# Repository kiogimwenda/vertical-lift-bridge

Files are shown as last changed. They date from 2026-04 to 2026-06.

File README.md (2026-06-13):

# Vertical Lift Bridge — Control System (Group 7)

**EEE2412 / ECE 4.2 — Microprocessors II Course Project**

A scale-model **vertical lift bridge**: a road bridge whose deck rises vertically
between two towers to let vessels pass underneath, then lowers to restore road
traffic. The system is driven by an **ESP32-WROOM-32** running a real-time,
multi-task FreeRTOS firmware with a safety-first architecture, an LVGL
touchscreen HMI, and a 3D-printed mechanical assembly.

> **Project phase:** Breadboard/simulation is complete. The project is now in the
> **physical assembly phase** (perfboard soldering + 3D-printed enclosure). See
> [`docs/Perfboard_Assembly_Guide.md`](docs/Perfboard_Assembly_Guide.md).

---

## 1. What it does

1. Bridge sits **down**, road open, green light, barriers up (`IDLE`).
2. Operator presses **RAISE** (touchscreen or front-panel button).
3. Barriers close, amber→red lights, counterweight tanks balance (`ROAD_CLEARING`).
4. Motor drives the deck **up** to the top limit (`RAISING` → `RAISED_HOLD`).
5. Vessel passes; operator presses **LOWER**; deck descends to the bottom limit
   (`LOWERING`). Lowering is **blocked** while a vessel is detected approaching.
6. Barriers open, green light, back to `IDLE` (`ROAD_OPENING`).

A hardware **E-stop**, a motor-cutoff **relay**, a **watchdog**, and a 16-flag
**fault register** can interrupt the cycle at any point.

The system currently runs in **manual mode** — the operator initiates raise/lower.
The quad **laser break-beam** array provides vessel-direction sensing that feeds
the marine alert and the "safe to lower" interlock.

---

## 2. Repository layout

```
firmware/          Main ESP32 application (PlatformIO + Arduino framework)
  src/
    main.cpp             Boot, FreeRTOS task creation, the 7 tasks
    system_types.h       SINGLE SOURCE OF TRUTH: states, events, faults, SharedStatus
    pin_config.h         SINGLE SOURCE OF TRUTH: all GPIO assignments
    fsm/                 Table-driven 9-state machine (engine + guards + actions)
    motor/               L298N H-bridge + timer-based deck position + runaway guard
    sensors/             Quad laser break-beam direction inference
    counterweight/       Pure-software water-tank balance simulation
    traffic/             74HC595 road traffic lights + buzzer (buzzer pin disabled)
    hmi/                 LVGL touchscreen display + 5-button resistor-ladder input
    safety/              Interlocks (E-stop/relay/servos), fault register, watchdog
cad/               13 parametric OpenSCAD parts → STL/3MF + print guide
mechanical/        Assembly photos
bom/               Bill of materials + shopping list
docs/              Design docs + perfboard assembly/wiring guide + known limitations
member_guides/     Per-member build & theory guides
Simulations/       SDL2 desktop LVGL mock for presentations
```

---

## 3. Hardware & pin map

Single source of truth: [`firmware/src/pin_config.h`](firmware/src/pin_config.h) (v3.0 map).

| Subsystem | Signal | GPIO | Notes |
|---|---|---|---|
| **Motor (L298N dual H-bridge)** | IN1 (up) | 25 | LEDC ch0, 13-bit, 4 kHz; ENA tied high |
| | IN2 (down) | 26 | LEDC ch1 |
| | Safety relay | 32 | de-energised cuts motor power |
| | ~~Deck-position pot~~ | 35 | **omitted** — timer-based positioning; spare |
| | ~~Limit switches~~ | 39 | **omitted** — timer-based end-stops; spare |
| **TFT ILI9341 (SPI)** | SCK / MOSI / MISO | 14 / 13 / 12 | |
| | CS / DC | 15 / 2 | RST→EN, BL→3V3 in hardware |
| | Touch CS (XPT2046) | 33 | IRQ polled |
| **Laser break-beam ×4** | LDR1–4 | 18 / 19 / 21 / 22 | upstream A/B, downstream A/B |
| **Traffic lights (74HC595)** | DATA / CLK / LATCH | 23 / 4 / 27 | OE→GND, MR→3V3; Q0–Q2 road (marine not implemented) |
| **Servos (SG90 ×2)** | shared PWM | 16 | both barriers driven by one channel (mirror) |
| **Buzzer** | — | −1 (disabled) | freed to preserve UART TX0 |
| **Operator panel** | 5-button R-ladder | 34 | ADC1_CH6 |
| **E-stop** | NC mushroom button | 36 | input-only, ISR on CHANGE |
| **Spare** | — | 17 | unused (vision module omitted) |

**Power:** 12 V barrel jack → LM2596 buck → 5 V rail → AMS1117 → 3.3 V rail.
Build the power planes and verify rails with a multimeter **before** connecting
any logic — see the perfboard guide.

---

## 4. Firmware architecture

Seven FreeRTOS tasks share one mutex-guarded status struct (`g_status`) and three
queues (events, motor commands, HMI commands).

| Task | Core | Prio | Rate | Responsibility |
|---|---|---|---|---|
| `task_safety` | 0 | 5 | 20 Hz | interlocks, fault eval, watchdog check, panel scan; lights+buzzer @ 10 Hz |
| `task_fsm` | 0 | 4 | event + 100 ms tick | runs the state machine |
| `task_motor` | 0 | 4 | ~50 Hz | applies motor cmds, reads pot, stall detect, limit events |
| `task_sensors` | 0 | 3 | 20 Hz | laser sampling + direction inference |
| `task_counterweight` | 0 | 2 | 20 Hz | water-tank fill/drain simulation |
| `task_telemetry` | 0 | 1 | 1 Hz | uptime |
| `task_hmi` | 1 | 2 | ~20 Hz | LVGL tick/flush/refresh, operator-command handling |

Core 0 hosts safety + control; Core 1 is reserved for the LVGL HMI so display
work cannot stall the safety loop. A hardware Task Watchdog Timer (5 s) backstops
a software per-task watchdog (1.5 s hang threshold → `interlocks_force_safe()`).

### State machine

`IDLE → ROAD_CLEARING → RAISING → RAISED_HOLD → LOWERING → ROAD_OPENING → IDLE`,
plus `FAULT`, `ESTOP`, and a boot-time `INIT`. `EVT_ESTOP_PRESSED` and
`EVT_FAULT_RAISED` are evaluated before all normal transitions. See
[`fsm/fsm_engine.cpp`](firmware/src/fsm/fsm_engine.cpp).

---

## 5. Build & flash

Requires [PlatformIO](https://platformio.org/).

```bash
cd firmware
pio run -e vlb_main            # compile
pio run -e vlb_main -t upload  # flash (hold BOOT if needed)
pio device monitor -b 115200   # serial logs
```

Optional ESP32-CAM companion (separate board):

```bash
cd firmware_cam
pio run -t upload
```

Key build config (`firmware/platformio.ini`): `espressif32@6.7.0`, `esp32dev`,
240 MHz, `huge_app.csv` partition, C++17. Libraries: TFT_eSPI 2.5.43, LVGL 9.2.2,
ArduinoJson 7.2.1. Last verified build: **RAM 33.2 %, Flash 19.3 %**.

---

## 6. Operator controls

- **Touchscreen (HOME / OPS / CW / SET tabs):** RAISE / LOWER / HOLD buttons,
  deck-height bar, marine sensor LEDs, traffic-light stack, motor PWM gauge,
  counterweight tank bars, settings (auto-mode, dark-mode, brightness). Tap the
  blue header bar for a deck-height / motor-PWM popup.
- **5-button resistor-ladder panel (GPIO 34):** RAISE, LOWER, HOLD, CLEAR-FAULT,
  NEXT-SCREEN — a defence-in-depth path that works even if the touch panel cracks.
- **E-stop mushroom button:** hardware-latched; also cuts the motor relay.

---

## 7. Known limitations

The firmware ships with honest, documented trade-offs forced by the ESP32 GPIO
budget and the BOM: no motor current sense on the L298N, no rail-voltage
telemetry, **no position pot or limit switches** (deck height is timer-estimated
and re-synced to the end-stops each traverse), open-loop barriers, and a shared
servo pin. The vision module is omitted from this build. Each trade-off is
recorded in [`docs/known_limitations.md`](docs/known_limitations.md).

---

## 8. Team & module ownership

| Member | Area | Primary modules |
|---|---|---|
| **M1 — George** | System & FSM | `main.cpp`, `fsm/` |
| **M2 — Eugene** | Mechanism | `motor/`, `counterweight/` |
| **M3 — Cindy** | Sensing | `sensors/laser` |
| **M4 — Abigael** | Traffic & HMI | `traffic/`, `hmi/` |
| **M5 — Ian** | Power & Safety | `safety/`, PCB, power |

Per-member guides are in [`member_guides/`](member_guides/).

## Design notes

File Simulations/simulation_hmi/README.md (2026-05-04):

# VLB HMI Software Simulation

This is a standalone PC-based simulation of the Vertical Lift Bridge dashboard. It uses the actual firmware data structures and LVGL graphics to emulate the bridge behavior on your Windows desktop.

## Prerequisites

1.  **VS Code + PlatformIO** (Already installed).
2.  **SDL2 Library for Windows**:
    *   Download `SDL2-devel-2.x.x-mingw.zip` from the [SDL2 Releases page](https://github.com/libsdl-org/SDL/releases).
    *   Extract it to a folder (e.g., `C:\SDL2`).
    *   Add the `bin` folder (e.g., `C:\SDL2\x86_64-w64-mingw32\bin`) to your **Windows Environment PATH**.
    *   Copy `SDL2.dll` from the `bin` folder into this `simulation_hmi` directory.

## How to Run

1.  Open VS Code.
2.  Go to the **File > Open Folder...** and select this `simulation_hmi` directory.
3.  Wait for PlatformIO to initialize the project.
4.  Click the **PlatformIO: Build** button (Checkmark icon) in the bottom status bar.
5.  Click the **PlatformIO: Run** button (Arrow icon) to launch the simulation window.

## Simulation Features

- **Real-time Bridge Logic**: Clicking "RAISE" in the OPS tab will simulate the motor winding cables, updating the height bar and current meter.
- **Modern Industrial Design**: Dark-mode UI with high-contrast status indicators.
- **Shared Data Model**: Uses the exact `SharedStatus_t` struct from the main project.
- **Hardware Mocks**: Simulated ADC noise and position tracking.

## Layout

- **HOME**: Visual representation of the deck height and road traffic lights.
- **OPS**: Manual controls (Raise/Lower/Hold) and motor current gauge.
- **VISION**: (Stub) Visualizes camera detection events.
- **DIAG**: (Stub) System health and fault register.
- **SET**: (Stub) HMI preferences.

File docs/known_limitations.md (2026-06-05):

# Known Limitations

Honest, documented trade-offs in the current build. Each entry lists the
limitation, why it exists, how the firmware mitigates it, and any procedure the
operator must follow.

---

## L1 — No motor current sensing
- **Cause:** The L298N module exposes no MCU-facing current-sense output (its
  SENSA/SENSB pins are shunted to ground on the module).
- **Effect:** `FAULT_OVERCURRENT` is never raised; `motor_current_ma` is always 0.
- **Mitigation:** The L298N's on-chip thermal shutdown protects the bridge, and
  the timer runaway-guard (`FAULT_STALL`, see L3) bounds how long the motor may
  be driven.

## L2 — No deck-position potentiometer, no limit switches (timer-based positioning)
- **Cause:** The position pot (GPIO 35) and limit switches (GPIO 39) are omitted
  from this build. Both pins are left as reserved spares (not reassigned).
- **Effect:** Deck height is *estimated*, not measured. There is no physical
  end-stop detection.
- **Mitigation:** `motor/motor_driver.cpp` integrates height from motor run-time
  using `DECK_RAISE_TIME_MS` / `DECK_LOWER_TIME_MS`. The estimate is pinned hard
  to `0` / `DECK_HEIGHT_MAX_MM` and a virtual `EVT_TOP/BOTTOM_LIMIT_HIT` is
  emitted whenever a traverse completes, so error re-synchronises twice per
  cycle and cannot accumulate.
- **Operator procedure:** **Park the deck at the bottom (0 mm) before power-off.**
  The firmware assumes the deck is fully down at boot. Powering on while raised
  will make the height read low until the next full lower re-syncs it.
- **Calibration:** Bench-measure the full-travel times at the operating PWM
  duties and update `DECK_RAISE_TIME_MS` / `DECK_LOWER_TIME_MS` in
  `system_types.h`. This is what makes the HMI deck-height readout accurate.

## L3 — Runaway guard replaces true stall detection
- **Cause:** With no position feedback a genuine mechanical stall is invisible.
- **Mitigation:** If a move runs longer than a full traverse +
  `MOTION_TIMEOUT_MARGIN_MS`, `FAULT_STALL` is raised and the FSM trips to FAULT
  (relay cut). This bounds worst-case motor drive into a hard stop.

## L4 — No rail-voltage monitoring
- **Cause:** No GPIO/ADC is allocated to a high-impedance voltage divider.
- **Effect:** `rail_*_volts` fields hold the `-1.0f` "not measured" sentinel.
- **Mitigation:** ESP32 internal brownout detector + LM2596/AMS1117 internal
  current/thermal limits provide hardware-level protection.

## L5 — Open-loop barrier servos
- **Cause:** Two SG90 servos share one PWM channel (GPIO 16) and have no
  position feedback.
- **Mitigation:** A deterministic software sweep (~40°/s) drives the angle; a
  barrier watchdog raises `FAULT_BARRIER_TIMEOUT` if the sweep does not reach
  its target within `BARRIER_TIMEOUT_MS` (catches a stalled safety task rather
  than a stuck servo, since the sweep itself is deterministic).

## L6 — Buzzer disabled
- **Cause:** `PIN_BUZZER` is `-1` to preserve UART TX0 (GPIO 1) for the serial
  monitor. Audible alerts are therefore not emitted.

## L7 — Vision module omitted
- **Cause:** The ESP32-CAM vision path is omitted from this build. UART2 / GPIO
  17 is left as a spare. `FAULT_VISION_LINK_LOST` is reserved but never set.
- **Effect:** Vessel detection relies solely on the quad laser break-beam.

## L8 — Manual lowering only
- **Cause:** Lowering from `RAISED_HOLD` is operator-initiated by design, guarded
  by `fsm_guard_safe_to_lower()` (no auto-lower). `EVT_HOLD_TIMEOUT` /
  `HOLD_TIMEOUT_MS` are reserved but unused — the bridge will not auto-lower onto
  an approaching vessel.

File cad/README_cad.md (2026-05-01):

# /cad — CAD pipeline documentation

All files in this folder are generated by **OpenSCAD 2021.01 +**.
Source files (`.scad`) are parametric — to change a dimension, edit `00_common.scad`
and re-render. To re-render every part:

```bash
cd /cad/scad
for f in 0[1-9]_*.scad 1[0-3]_*.scad; do
    openscad -o "../stl/${f%.scad}.stl" "$f"
done
```

> **Note on the 2-manifold warnings.**  OpenSCAD 2021.01 CGAL emits warnings for the tower lower
> section, the pulley wheel, and the TFT mount because some boolean cuts produce coincident
> faces. **The exported STLs slice cleanly in Cura 5.7 and PrusaSlicer 2.7** — both
> self-heal minor manifold issues. If you ever need a perfectly-watertight STL for hand-checking
> in MeshLab, use `Filters → Cleaning → Repair Non-Manifold Edges`.

---

## Per-part print settings

All settings are for **PLA filament, 0.4 mm nozzle**. Layer height, infill, walls, supports,
and orientation given. Estimated print times are for a Creality Ender 3 / Elegoo Neptune class
printer at default speed (50 mm/s).

| Part | Layer | Infill | Walls | Supports | Orientation | Est. time | Filament |
|---|---|---|---|---|---|---|---|
| 01_tower_left.stl | 0.20 mm | 25 % gyroid | 4 | None | Lay flat (long axis on bed) | 9 h 50 m | 165 g |
| 02_tower_right.stl | 0.20 mm | 25 % gyroid | 4 | None | Lay flat | 9 h 30 m | 158 g |
| 03_bridge_deck_section.stl | 0.20 mm | 30 % gyroid | 3 | None | Lay flat | 4 h 10 m | 64 g |
| 04_counterweight_left.stl | 0.20 mm | 15 % grid | 3 | None | Stand vertical (60 mm tall) — fill access hole faces up | 1 h 50 m | 18 g (shell only — fill at assembly) |
| 05_counterweight_right.stl | 0.20 mm | 15 % grid | 3 | None | Stand vertical | 1 h 50 m | 18 g |
| 06_pulley_wheel.stl | 0.16 mm | 35 % gyroid | 4 | **Auto-tree on hub overhang** | Hub up | 1 h 25 m | 14 g |
| 07_motor_mount.stl | 0.20 mm | 30 % gyroid | 4 | **Yes — 50° threshold, support inside motor cradle** | Cradle bores aligned with X | 2 h 05 m | 22 g |
| 08_cable_guide.stl | 0.16 mm | 50 % gyroid | 4 | None (slot is open) | As exported | 35 m | 7 g |
| 09_road_barrier.stl | 0.16 mm | 25 % grid | 3 | None | Lay flat (arm + post separately) | 1 h 30 m | 12 g |
| 10_base_plate_section.stl | 0.28 mm draft | 12 % grid | 3 | None | Lay flat (largest face down) | 4 h 20 m / panel × 6 = 26 h | 70 g/panel × 6 = 420 g |
| 11_pcb_enclosure.stl | 0.20 mm | 25 % grid | 3 | None (lid prints with cavity facing up) | Both halves cavity-up on bed | 4 h 10 m | 50 g |
| 12_camera_mount.stl | 0.20 mm | 30 % gyroid | 4 | **Yes — for cradle 25° tilt overhang** | Gantry post laid down; cradle as exported | 5 h 30 m | 65 g |
| 13_tft_display_mount.stl | 0.20 mm | 30 % gyroid | 4 | **Yes — for tilted cradle (35° overhang)** | Base flange down | 3 h 45 m | 38 g |

**Total filament: ≈ 1.05 kg PLA  → 1× 1 kg spool + ~50 g overflow  → buy 1.5 kg.**

**Total print time: ≈ 70 hours** if printed sequentially on one printer. With two printers
running in parallel during Weeks 1–3 the build is comfortably done by start of Week 4.

---

## Brass-insert parts list (M3, OD 4.2 mm × 5 mm)

The following parts have heat-set insert pockets — drop in a brass insert with a soldering
iron at 220 °C before final assembly:

- 10_base_plate_section.stl × 6  (5 inserts per panel on the +X edge = 30 inserts)
- 11_pcb_enclosure.stl  (4 inserts in the base for the lid screws)
- **Total: 34 brass inserts** — see BOM line "M3 brass heat-set inserts × 50 (incl. spares)".

---

## Post-processing per part

| Part | Post-process |
|---|---|
| Towers | Sand mating dovetail (320 grit) for press-fit; cut linear-rail T-slots clean with a small file |
| Deck | Light sand of road grooves; spray-paint road markings if desired |
| Counterweight shells | After printing, fill cavity with **2× M8 hex nut + 4× M8 washer** + 5 g lead fishing weight, weigh on kitchen scale, add/remove until **120 g ± 2 g**, then plug fill hole with PLA glue (Weld-On 3 or super glue) |
| Pulley | Ream Ø6.2 mm bore with 6 mm reamer for clean shaft fit; sand groove with 600 grit so cable runs smoothly |
| Motor mount | Heat-set inserts; press JGA25-370 motor in (light interference fit) |
| Cable guide | Open 1.4 mm slot enough to thread cable through |
| Road barrier | Glue or screw the post to base plate; servo press-fits in pocket |
| PCB enclosure | Heat-set 4× brass inserts in lid screw bosses; fit board on standoffs and tap each for M3 |
| Camera mount | Glue cradle to top of gantry post once cable is threaded; 4× M3 self-tap to hold ESP32-CAM board |
| TFT mount | 4× M3 self-tap holds the TFT module — do not over-tighten; inspect tilt is 35° ± 1° with a digital protractor |

---

## How a future change is made

1. Edit a constant at the top of `00_common.scad` (say `TOWER_H = 380`).
2. Re-render only the affected parts: `openscad -o ../stl/01_tower_left.stl 01_tower_left.scad`
3. Commit both the updated `.scad` and `.stl` to Git.

---

## Files in this directory

```
cad/
├── scad/
│   ├── 00_common.scad
│   ├── 01_tower_left.scad … 13_tft_display_mount.scad
│   └── assembly.scad
├── stl/
│   └── (13 production STLs, one per .scad)
├── step/
│   └── *.3mf  (CAD-interchange format; STEP is not a native OpenSCAD output, 3MF is the
│               equivalent on this toolchain)
└── README_cad.md (this file)
```

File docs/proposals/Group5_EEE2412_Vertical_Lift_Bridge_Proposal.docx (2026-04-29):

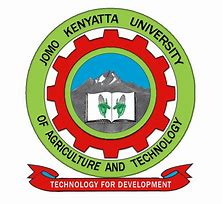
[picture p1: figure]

JOMO KENYATTA UNIVERSITY OF AGRICULTURE AND

TECHNOLOGY

SCHOOL OF ELECTRICAL, ELECTRONIC AND INFORMATION ENGINEERING

DEPARTMENT OF ELECTRONIC AND COMPUTER ENGINEERING

PROJECT PROPOSAL

GROUP 5 MEMBERS

NAME | ADMISSION NUMBER
MUGAISI EUGENE MURULI | ENE212-0083/2020
KIOGORA IAN MWENDA | ENE212-0251/2021
OCHIERE GEORGE JOHN | ENE212-0218/2021
KOECH CINDY CHEBET | ENE212-0069/2020
KIRUI ABIGAEL CHEROTICH | ENE212-0070/2020

COURSE: B.Sc. ELECTRONIC AND COMPUTER ENGINEERING

EEE 2412

MICROPROCESSORS II

TITLE: AUTOMATIC VERTICAL LIFT BRIDGE CONTROL SYSTEM

DATE: April 2026

1. EXECUTIVE SUMMARY

This proposal presents the Automatic Vertical Lift Bridge Control System as Group 5’s project for the Microprocessors II unit (EEE 2412). The system automates the complete operation of a scale-model vertical lift bridge: it detects approaching vessels using directional ultrasonic sensors, stops road traffic with sequenced traffic lights and servo-actuated barriers, raises the bridge deck vertically between four tower structures in mechanically synchronised motion, allows vessel transit through the cleared waterway, then lowers the deck and restores normal road traffic flow—all without human intervention.

The bridge mechanism employs a single JGA25-370 geared DC motor whose torque is mechanically distributed to four T8 trapezoidal lead screws—one per tower—via a network of a closed-loop GT2 timing belt and four GT2 pulleys. The belt runs at tower-top level, high above the waterway, ensuring zero obstruction to vessel transit. Because the four screws are rigidly coupled through this mechanical linkage, they turn at exactly the same rate without any electronic synchronisation. The self-locking property of the trapezoidal thread profile means the deck holds its position if power is lost, providing inherent safety without counterweights or braking systems.

Directional vessel detection uses a dual-beam ultrasonic sensor arrangement at each end of the waterway. Two HC-SR04 sensors are mounted 30 mm apart on a common bracket at each station. By analysing which beam breaks first, the firmware determines the vessel’s heading, enabling the system to raise the bridge only for approaching vessels. This design correctly handles simultaneous bidirectional vessel traffic.

The entire control electronics—ESP32-WROOM-32 microcontroller, DRV8871 H-bridge motor driver, 74HC595 LED shift register, CP2102N USB-UART bridge, LM2596 buck converter, AMS1117 LDO regulator, safety relay with MOSFET gate driver, and all sensor interface circuits—are integrated onto a single custom-designed Printed Circuit Board (PCB), fabricated by JLCPCB to professional standards. The ESP32 runs FreeRTOS with seven priority-scheduled tasks across dual CPU cores for real-time motor control, sensor polling, traffic management, safety monitoring, and Human Machine Interface (HMI) display on a 2.8-inch ILI9341 TFT screen. An operator panel with pushbuttons and an emergency stop provides local control authority.

The total estimated component cost is approximately KES 17,300, shared across five team members at approximately KES 3,460 per person.

2. PROBLEM STATEMENT

Movable bridges are critical infrastructure elements at waterway crossings, enabling both road traffic and vessel navigation to share the same corridor. In Kenya and across the developing world, many such crossings are operated manually by an attendant who must be physically present to observe vessel approach, halt road traffic, and operate the bridge mechanism. This manual operation introduces three categories of recurring problems:

• i. Safety risk from human error. A delayed response by the attendant can result in vehicles being stranded on a raising bridge deck, or a vessel colliding with a bridge that was not raised in time. Manual systems have no interlock to verify that the deck is clear of vehicles before raising, or that traffic barriers are fully lowered before the deck moves.

• ii. Synchronisation failure in multi-point lift systems. Vertical lift bridges require multiple lift points to move in precise synchronisation. Manual or poorly controlled systems risk deck tilting, guide rail binding, and structural stress when lift points move at different rates. A height discrepancy of as little as 15 mm across a model-scale deck is sufficient to cause visible tilting and mechanical jamming.

• iii. Inability to determine vessel intent. Conventional single-sensor detection systems cannot distinguish between a vessel approaching the bridge (which requires a raise) and a vessel departing the area (which requires no action). This leads to unnecessary bridge raises that disrupt road traffic without cause, and cannot handle simultaneous bidirectional vessel traffic.

This project solves all three problems through full automation: a mechanically-locked four-point lift system that physically cannot desynchronise, a dual-beam directional sensor array that determines vessel heading at each end of the waterway independently, and a comprehensive interlock chain that verifies every safety condition before permitting deck movement.

3. SYSTEM OVERVIEW

The system is centred on an ESP32-WROOM-32 microcontroller that reads sensors, executes a finite state machine (FSM), drives actuators, enforces safety interlocks, and presents system status on a TFT display. The physical bridge is a scale model built on a 900 mm × 600 mm plywood base platform with a 150 mm-wide waterway channel, four tower structures (each 300 mm tall), and a 200 mm × 120 mm bridge deck that travels 180 mm vertically between the fully-lowered and fully-raised positions.

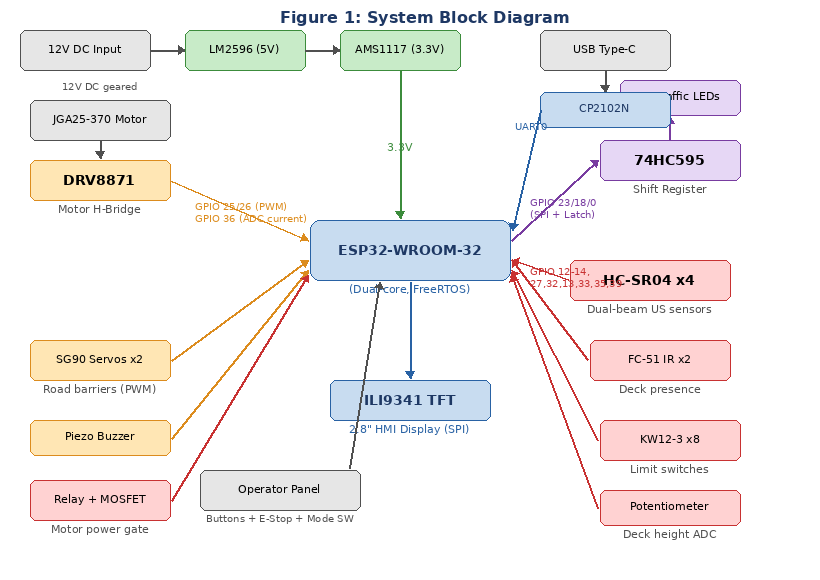
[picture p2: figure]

Figure 1: System block diagram showing all components and their connections to the ESP32

3.1 Vertical Lift Mechanism

Unlike a bascule (drawbridge) design where leaves pivot upward on hinges, a vertical lift bridge raises the entire deck horizontally between tower structures. The deck remains perfectly level throughout its travel. This design was selected for its mechanical precision, inherent stability, and the elimination of complex linkage geometry.

Drive system: A single JGA25-370 DC geared motor (12 V, 60 RPM, 1.2 kg·cm torque) is mounted at the base of Tower A-Left. The motor shaft couples directly to a T8 trapezoidal lead screw (2 mm pitch, 4-start giving 8 mm linear travel per revolution) that runs vertically through the tower. At the tower top, a GT2 20-tooth pulley at the top of the screw shaft engages a GT2 6 mm timing belt. This belt forms a closed rectangular loop connecting pulleys at the tops of all four towers, synchronising all lead screws to identical rotation’s lead screw.

Torque distribution to all towers: The GT2 timing belt forms a closed rectangular loop at tower-top level, approximately 380 mm above the base platform and well above maximum vessel clearance height. The belt path runs from the Tower A-Left pulley along Bank A to Tower A-Right, then crosses the waterway to Tower B-Right, runs along Bank B to Tower B-Left, and crosses back to Tower A-Left. The belt crosses the waterway twice but only at the very top of the towers, leaving the entire channel clear below. Each of the four pulleys drives its tower’s lead screw, so one motor rotation translates to identical screw rotation at all four lift points.

Mechanical synchronisation: Because all four lead screws are rigidly coupled through the timing belt and pulley network, they are physically constrained to turn at exactly the same angular velocity. This is a fundamental mechanical property of synchronous belt coupling—it is not dependent on software, sensors, or feedback loops. The deck rides on four threaded brass nut blocks (one per screw) with guide blocks at all four corners sliding on vertical aluminium guide rails to prevent any tilting, rocking, or rotation.

Self-locking safety: The trapezoidal thread profile of the T8 screw has a helix angle smaller than the friction angle of the brass-on-steel interface. This means the screw is non-backdrivable: the load (deck weight) cannot cause the screw to rotate in reverse. If power is lost or the motor is de-energised for any reason, the deck holds its position indefinitely without any additional braking mechanism. This eliminates the need for counterweights, electromagnetic brakes, or mechanical catches.

Speed and travel: At 60 RPM with an 8 mm lead, the deck moves at 8 mm/s. A full 180 mm raise takes approximately 22.5 seconds, which is appropriate for a scale-model demonstration. The motor produces approximately 0.12 N·m of torque, while the deck (approximately 250 g fully loaded) requires only 0.008 N·m through the screw mechanism—a safety factor of 15×.

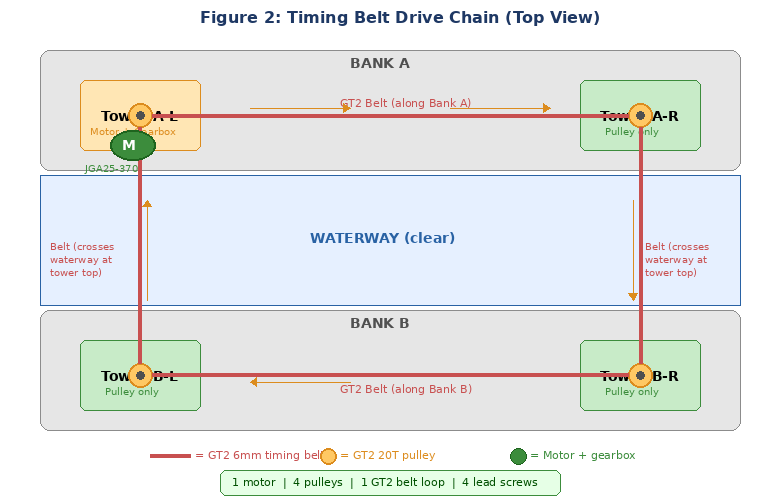
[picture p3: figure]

Figure 2: GT2 timing belt drive chain — single motor drives all four screws via a belt loop at tower-top level

3.2 Directional Vessel Detection

A fundamental requirement for an automated bridge is the ability to determine whether a detected vessel requires the bridge to be raised. A vessel approaching the bridge needs passage; a vessel departing does not. Conventional single-sensor systems cannot make this distinction. The SBPCS solves this using a dual-beam sensor station at each end of the waterway.

Sensor station layout: Each station consists of two HC-SR04 ultrasonic distance sensors mounted 30 mm apart along the waterway axis on a common rigid bracket, with both sensors aimed across the channel perpendicular to the waterway flow. The two sensors are designated Beam A (the outer beam, closer to open water) and Beam B (the inner beam, closer to the bridge). The two stations are designated Upstream (on the approach side) and Downstream (on the departure side).

Direction determination: When a vessel passes through a sensor station, it breaks Beam A and Beam B in sequence. The time difference between the two beam-break events, combined with which beam breaks first, determines the vessel’s direction of travel:

• i. Approaching vessel (upstream station): Beam A triggers before Beam B. This sequence indicates the vessel is moving from open water toward the bridge. The firmware posts an EVT_VESSEL_DETECTED event to the FSM event queue, initiating the bridge raise cycle.

• ii. Departing vessel (upstream station): Beam B triggers before Beam A. This reversed sequence indicates the vessel is moving away from the bridge. The firmware discards this event—no bridge raise is required.

• iii. Bidirectional simultaneous transit: Each sensor station determines direction independently. If a vessel approaches from upstream while another departs downstream, the upstream station correctly detects the approach (Beam A then B) and the downstream station independently detects the departure (Beam B then A at that station). The two stations operate asynchronously. The downstream station’s detection of a vessel passing through (in any direction) generates the EVT_VESSEL_PASSED event that signals the FSM to begin the bridge lowering sequence.

• iv. Simultaneous beam triggering: If both beams at a single station trigger within less than 50 ms of each other, the firmware classifies this as sensor noise, wave splash, or a non-vessel obstruction (e.g., floating debris) and discards the event. A genuine vessel at any plausible speed in a model waterway takes at least 100 ms to traverse the 30 mm beam spacing, so this rejection threshold has a 2× safety margin.

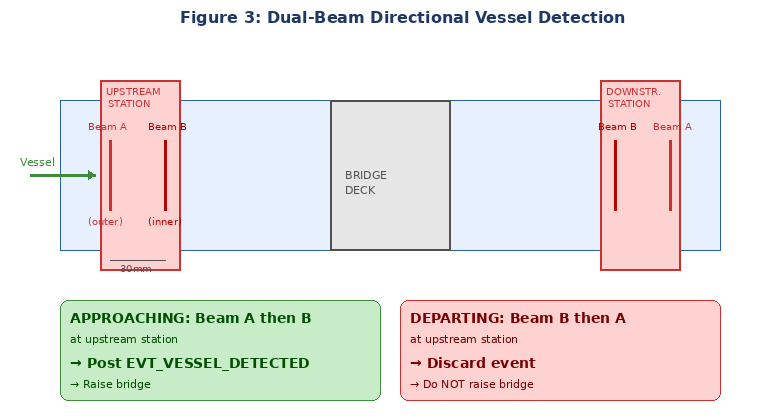
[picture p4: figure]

Figure 3: Dual-beam directional vessel detection — beam sequence determines vessel heading

3.3 Operating Modes

Mode | Trigger | System Behaviour
AUTO | Default on boot | Bridge controlled automatically by vessel detection, with full safety interlock verification before each raise/lower cycle.
MANUAL | Toggle switch on operator panel | Operator directly commands Raise, Lower, or Stop via dedicated pushbuttons. All safety interlocks remain enforced.
EMERGENCY STOP | E-stop button pressed | All motors immediately de-energised via hardware relay path independent of microcontroller. System latched until E-stop released and Reset pressed.
FAULT | Fault detected by safety watchdog | Motors stopped. Fault code and description displayed on TFT. Latched until fault condition clears and operator presses Reset.

4. DETAILED COMPONENT DESCRIPTION

This section describes every major component in the system, explaining what it does, how it works at a fundamental level, and how it is electrically connected to the rest of the system.

4.1 ESP32-WROOM-32 Microcontroller

What it is: The ESP32-WROOM-32 is a dual-core 32-bit Xtensa LX6 microcontroller module manufactured by Espressif Systems. It integrates WiFi and Bluetooth radios (not used in this project), 520 KB of SRAM, 4 MB of flash memory, 34 programmable GPIO pins, two 12-bit ADC units, four SPI interfaces, two I²C interfaces, two UART interfaces, and 16 PWM channels via the LEDC peripheral. It operates at 240 MHz and supports FreeRTOS for concurrent multitasking.

What it does in this system: The ESP32 is the central control unit. It runs seven FreeRTOS tasks that collectively: read all sensors (ultrasonic, IR, limit switches, potentiometer, current sense), execute the finite state machine that governs bridge operation, generate PWM signals to control motor speed, drive the shift register for traffic LEDs, control servo barrier positions, monitor safety conditions, and render the HMI display on the TFT screen.

How it connects: The ESP32 module is soldered directly to the custom PCB. Its 3V3 power pin connects to the 3.3 V rail provided by the AMS1117 LDO, with a 100 nF ceramic decoupling capacitor placed within 5 mm of the pin. All ground pins connect to the PCB ground plane. The EN (enable) pin is pulled high to 3.3 V through a 10 kΩ resistor with a 100 nF RC delay capacitor to ground for clean power-on reset. GPIO 0 has a 10 kΩ pull-up to 3.3 V (must be HIGH at boot for normal operation). GPIO 2 has a 10 kΩ pull-down (must be LOW at boot). GPIO 12 has a 10 kΩ pull-down (MTDI strapping pin, must be LOW for 3.3 V flash). GPIO 15 has a 10 kΩ pull-up (MTDO strapping pin). The antenna end of the module overhangs the PCB edge with a 7 mm copper-free keepout zone to avoid detuning the antenna.

4.2 DRV8871 Motor Driver IC

What it is: The DRV8871 is a brushed DC motor driver IC manufactured by Texas Instruments. It contains a full H-bridge capable of driving motors up to 3.6 A peak current at up to 45 V. It requires only two control inputs (IN1 and IN2) and provides a current-sense output (VPROPI).

What it does: It converts the ESP32’s low-power GPIO signals into high-current drive signals for the JGA25-370 motor. By applying PWM to IN1 with IN2 held LOW, the motor rotates in one direction (raising the deck). Reversing the signals (PWM on IN2, IN1 LOW) reverses the motor (lowering the deck). Setting both LOW allows the motor to coast. The VPROPI pin outputs a voltage proportional to the motor current (V = I × R_sense), enabling the ESP32 to monitor current for overcurrent and stall detection.

How it connects: The DRV8871 VM (motor voltage) pin connects to the 12 V motor power rail after the safety relay K1. A 100 nF ceramic decoupling capacitor is placed across VM to GND as close to the pin as possible. IN1 connects to ESP32 GPIO 25, IN2 to GPIO 26—both configured as LEDC PWM outputs at 20 kHz with 8-bit resolution (0–255 duty cycle). OUT1 and OUT2 connect to a 2-pin screw terminal (J3) for the motor wires. VPROPI connects through a 1 Ω sense resistor to GND, with the junction fed to ESP32 GPIO 36 (ADC1_CH0). The ILIMIT pin connects through a 10 kΩ resistor to GND, setting the hardware current limit to approximately 1 A. The exposed thermal pad on the underside of the IC connects to the ground plane through four 0.3 mm thermal vias—this is critical for heat dissipation.

4.3 74HC595 Shift Register

What it is: The 74HC595 is an 8-bit serial-in, parallel-out shift register with a storage register and tri-state outputs. Data is shifted in one bit at a time on the rising edge of the shift clock (SRCLK), then all eight outputs update simultaneously when the storage clock (RCLK) is pulsed.

What it does: It drives eight traffic signal LEDs using only three ESP32 GPIO pins instead of eight. The eight outputs map to: QA = Road A Red, QB = Road A Yellow, QC = Road A Green, QD = Road B Red, QE = Road B Yellow, QF = Road B Green, QG = Marine Red, QH = Marine Green.

How it connects: VCC (pin 16) connects to 3.3 V with a 100 nF decoupling capacitor. GND (pin 8) connects to ground. SER/DS (pin 14, serial data input) connects to ESP32 GPIO 23. SRCLK/SHCP (pin 11, shift clock) connects to GPIO 18. RCLK/STCP (pin 12, latch clock) connects to GPIO 0. OE (pin 13, output enable, active LOW) is tied to GND so outputs are always enabled. SRCLR (pin 10, shift register clear, active LOW) is tied to VCC so the register is never cleared. Each of the eight outputs connects through a current-limiting resistor to an LED and then to GND. Resistor values are chosen for approximately 15 mA at 3.3 V: 68 Ω for red LEDs (V_f ≈ 2.0 V), 56 Ω for yellow LEDs (V_f ≈ 2.1 V), and 47 Ω for green LEDs (V_f ≈ 2.2 V). GPIO 23 and GPIO 18 are shared with the TFT display SPI bus; the 74HC595 uses a separate latch pin so there is no bus contention.

4.4 Power Supply System

12 V input: System power enters through a 5.5 mm × 2.1 mm barrel jack connector from a 12 V / 3 A DC wall adapter. An SS34 Schottky diode in series provides reverse polarity protection. A 100 µF/25 V electrolytic capacitor and a 100 nF ceramic capacitor across the 12 V rail provide bulk energy storage and high-frequency decoupling.

LM2596-5.0 buck converter (12 V → 5 V): The LM2596-5.0 is a fixed-output 5 V DC-DC step-down switching regulator capable of delivering 3 A. It operates by rapidly switching the input voltage on and off through an inductor (L1, 330 µH) and smoothing the output with a capacitor (C3, 220 µF/16 V). A 1N5824 Schottky diode (D1) provides the freewheeling current path when the internal switch is off. The feedback pin connects directly to the output for the fixed-5.0 version. A green LED with a 1 kΩ series resistor indicates that the 5 V rail is live. The 5 V rail powers: the servo motors, the HC-SR04 ultrasonic sensors, the relay coil, the buzzer, and feeds the AMS1117 LDO.

AMS1117-3.3 LDO regulator (5 V → 3.3 V): The AMS1117-3.3 is a fixed-output 3.3 V linear dropout regulator providing up to 800 mA. A 10 µF tantalum capacitor is placed on both the input and output pins within 5 mm for stability. The 3.3 V rail powers: the ESP32 module (peak ≈ 240 mA during WiFi TX, though WiFi is unused here, typical ≈ 80 mA), the 74HC595 shift register, the FC-51 IR sensors, and the potentiometer reference voltage.

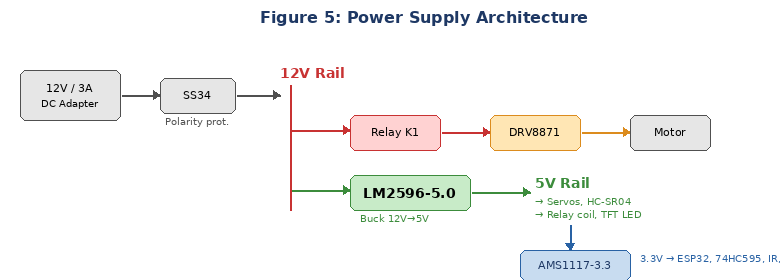
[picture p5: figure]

Figure 5: Power supply architecture — 12 V input stepped down to 5 V and 3.3 V rails

4.5 CP2102N USB-to-UART Bridge

What it is: The CP2102N is a USB-to-UART bridge IC by Silicon Labs that enables programming and debugging the ESP32 via a USB connection to a PC. It appears as a virtual COM port on the host computer.

How it connects: The USB Type-C connector’s D+ and D− lines connect to the CP2102N through 22 Ω series resistors. Two 5.1 kΩ resistors from CC1 and CC2 to GND identify the device as a USB sink (UFP). The CP2102N’s TXD pin connects to ESP32 GPIO 3 (RXD0) and RXD connects to GPIO 1 (TXD0). An auto-reset circuit using two 2N3904 NPN transistors allows the programming tool to automatically reset the ESP32 into download mode: DTR through a 100 nF capacitor drives Q1’s base (collector to GPIO 0), and RTS through a 100 nF capacitor drives Q2’s base (collector to EN).

4.6 HC-SR04 Ultrasonic Distance Sensors (×4)

What it is: The HC-SR04 is an ultrasonic ranging module that measures distance by emitting a 40 kHz ultrasonic pulse and timing how long it takes for the echo to return. It operates at 5 V and has four pins: VCC, GND, TRIG (trigger input), and ECHO (echo output). The ECHO pin outputs a 5 V pulse whose width in microseconds equals the round-trip time; distance in centimetres = pulse_width × 0.0343 / 2.

What they do: Four HC-SR04 sensors form two dual-beam stations (upstream and downstream). Each station detects vessels crossing the waterway and determines their direction of travel using the beam-sequence method described in Section 3.2.

How they connect: Each sensor’s VCC connects to the 5 V rail and GND to ground. Each TRIG pin connects directly to an ESP32 GPIO output (the ESP32 outputs 3.3 V, which exceeds the HC-SR04’s minimum HIGH threshold of 2.0 V). Each ECHO pin connects through an on-PCB voltage divider (1 kΩ series + 2 kΩ to GND) to an ESP32 GPIO input, reducing the 5 V ECHO signal to 5 × 2/(1+2) = 3.33 V, which is safe for the ESP32’s 3.3 V-tolerant inputs. The four sensors use GPIO 12/14 (upstream beam A), GPIO 27/32 (upstream beam B), GPIO 13/33 (downstream beam A), and GPIO 35/39 (downstream beam B) for their TRIG/ECHO pairs respectively. Each sensor connects to the PCB via a JST-XH 4-pin header (VCC, GND, TRIG, ECHO).

4.7 FC-51 IR Obstacle Sensors (×2)

What it is: The FC-51 is an infrared proximity sensor module that detects objects within a configurable range (typically 2–30 cm, adjustable via onboard potentiometer). It contains an IR LED transmitter and a photodiode receiver. When an obstacle reflects the IR beam back to the receiver, the module’s output pin goes LOW (active LOW logic).

What they do: Two FC-51 sensors are mounted at deck level, one on each side of the bridge deck. They detect whether any vehicles or objects are present on the deck surface. The bridge will not begin raising until both sensors report clear (output HIGH) for a sustained 2-second window, preventing vehicles from being stranded on a raising deck.

How they connect: VCC connects to 3.3 V, GND to ground, and OUT to ESP32 GPIO 21 (sensor A) and GPIO 22 (sensor B) configured with internal pull-up resistors. Each sensor connects via a JST-XH 3-pin header.

4.8 KW12-3 Microswitches — Limit Switches (×8)

What they do: Eight microswitches provide hardware end-of-travel protection—one at the top and one at the bottom of each tower’s screw travel. When the deck reaches a limit position, the nut block physically presses the switch lever. The normally-open (NO) contact closes, pulling the corresponding GPIO pin LOW through the switch. The firmware detects this via interrupt and immediately commands the motor to stop, preventing mechanical damage from overtravel.

How they connect: Each switch’s COM terminal connects to GND and NO terminal connects to an ESP32 GPIO pin configured with an internal pull-up resistor. When the switch is not pressed, the GPIO reads HIGH (pulled up internally). When pressed, the GPIO reads LOW (connected to GND through the closed switch). GPIO assignments: Tower A-L bottom = GPIO 16, A-L top = GPIO 17, A-R bottom = GPIO 5, A-R top = GPIO 19, and the remaining four for Towers B-L and B-R.

4.9 SG90 Micro Servos (×2)

What they do: Two SG90 servos actuate the road barriers at the approach roads to the bridge. Each servo rotates a barrier arm between 0° (barrier raised, road open) and 90° (barrier lowered, road blocked). The servo position is set by a PWM signal: a 50 Hz signal with a pulse width between 500 µs (0°) and 2400 µs (180°).

How they connect: Each servo has three wires: red (VCC, 5 V rail), brown (GND), and orange (signal). The signal wire connects to ESP32 GPIO 4 (Servo A) and GPIO 15 (Servo B). Each servo connects to the PCB via a JST-XH 3-pin header.

4.10 2.8-inch ILI9341 TFT Display

What it does: The ILI9341 is a 240×320 pixel colour TFT LCD driven over a 4-wire SPI interface at up to 40 MHz. It provides the primary Human Machine Interface visualisation, displaying: the current system state (e.g., IDLE, BRIDGE_RAISING, FAULT), a bar gauge showing deck height in millimetres, motor current reading, sensor status indicators (upstream/downstream/IR), active fault codes with descriptions, and the current operating mode (AUTO/MANUAL).

How it connects: VCC to 3.3 V, GND to ground. MOSI (data) to GPIO 23 (shared SPI bus with 74HC595), SCLK (clock) to GPIO 18 (shared), CS (chip select) to GPIO 15, DC (data/command select) to GPIO 2, RST (hardware reset) to GPIO 4, LED (backlight) to 5 V. The TFT_eSPI library handles CS assertion internally during SPI transactions. A mutex in the firmware prevents simultaneous SPI access between the display task and the shift register output task.

4.11 Safety Relay Circuit

What it does: The SRD-05VDC-SL-C relay acts as a power gate between the 12 V supply and the motor driver’s VM pin. When the relay is energised (coil powered), the normally-open contact closes and 12 V reaches the DRV8871. When de-energised, the contact opens and motor power is physically cut at the hardware level.

How it connects: The relay coil positive terminal connects to the 5 V rail. The coil negative terminal connects to the drain of a 2N7000 N-channel MOSFET. The MOSFET source connects to GND. The MOSFET gate connects through a 1 kΩ resistor to a junction point that is fed by both the ESP32 GPIO 33 (relay control output) and the E-stop button’s normally-closed contact. A 10 kΩ pull-down resistor on the gate ensures the MOSFET defaults to OFF if the GPIO is floating. A 1N4148 flyback diode across the relay coil (cathode to positive) protects the MOSFET from the inductive voltage spike when the coil de-energises. When GPIO 33 is HIGH and the E-stop is not pressed (NC contact closed), the gate voltage is HIGH, the MOSFET conducts, the relay energises, and motor power flows. If either GPIO 33 goes LOW or the E-stop is pressed (NC contact opens), the gate goes LOW, the MOSFET turns off, the relay de-energises, and motor power is cut—regardless of the microcontroller’s state.

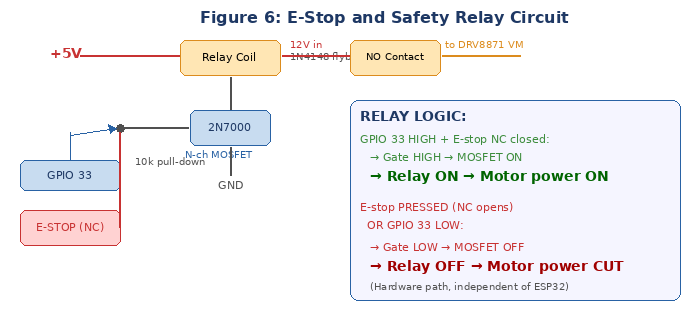
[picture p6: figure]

Figure 6: E-Stop and safety relay circuit — hardware-level motor power control independent of ESP32

5. SYSTEM ARCHITECTURE

5.1 Hardware Architecture

Component | Part Number | Function | Interface
Microcontroller | ESP32-WROOM-32 | Dual-core control, FreeRTOS | GPIO, ADC, SPI, UART
Motor Driver | DRV8871 | H-bridge, current sense | PWM GPIO 25/26, ADC GPIO 36
Shift Register | 74HC595 | 8-channel LED driver | SPI: GPIO 23/18/0
Buck Converter | LM2596-5.0 | 12 V → 5 V / 3 A | On-board DC-DC
LDO Regulator | AMS1117-3.3 | 5 V → 3.3 V / 800 mA | On-board LDO
USB-UART Bridge | CP2102N | Programming + serial debug | UART0: GPIO 1/3
US Sensors (upstream) | HC-SR04 ×2 | Dual-beam direction detect | GPIO 12/14, 27/32
US Sensors (downstream) | HC-SR04 ×2 | Dual-beam direction detect | GPIO 13/33, 35/39
Deck Presence | FC-51 IR ×2 | Vehicle detection on deck | GPIO 21, 22
Limit Switches | KW12-3 ×8 | End-of-travel hard stops | GPIO 16,17,5,19 + 4 more
Position Feedback | 10 kΩ potentiometer | Deck height measurement | ADC: GPIO 34
TFT Display | 2.8″ ILI9341 | HMI visualisation | SPI: GPIO 23/18/15/2/4
Servo Barriers | SG90 ×2 | Road barrier actuators | PWM: GPIO 4, 15
Buzzer | Active piezo | Alarm sound patterns | GPIO 2
Safety Relay | SRD-05VDC | Motor power gate | MOSFET gate: GPIO 33
Power Input | 12 V 3 A adapter | System power | Barrel jack
Geared Motor | JGA25-370 60RPM | Bridge lift drive | DRV8871 OUT1/OUT2
Lead Screws | T8×300 mm ×4 | Vertical lift mechanism | Coupled to motor via GT2 belt
GT2 Timing Belt | 6 mm wide, ~3 m loop | Torque distribution | Rectangular loop at tower tops
GT2 Pulleys | 20T aluminium ×4 | Screw-to-belt coupling | Mounted on each screw shaft

5.2 Firmware Architecture (FreeRTOS)

The ESP32 firmware runs seven concurrent FreeRTOS tasks distributed across both CPU cores. Tasks are coordinated through a mutex-protected SharedStatus_t structure and inter-task event queues (xQueueSend/xQueueReceive). The dual-core architecture places time-critical tasks (safety, FSM, motor, sensors) on Core 1, and less critical tasks (traffic, HMI) on Core 0.

Task | Core | Priority | Period | Function
Safety Watchdog | 1 | 25 (highest) | 5 ms | E-stop polling, overcurrent ADC check, limit switch ISR, anti-jam detection (current vs. position), FreeRTOS TWDT feed
FSM Engine | 1 | 24 | 10 ms | Table-driven state machine: reads event queue, evaluates guard condition function pointers, executes transition action callbacks, updates state
Motor Control | 1 | 23 | 10 ms | Reads potentiometer via ADC, applies PWM speed ramp (acceleration/deceleration), enforces soft position limits, outputs PWM to DRV8871
Sensor Poll | 1 | 22 | 20 ms | Sequences dual-beam ultrasonic measurements (Beam A then B at each station), debounces IR inputs, runs direction-determination algorithm, posts events
Traffic Control | 0 | 15 | 50 ms | Shifts LED pattern byte to 74HC595, sweeps servo positions in 3° increments with 30 ms delay, generates buzzer alarm patterns per state
HMI Input | 0 | 12 | 50 ms | Debounces Mode, Raise, Lower, Reset pushbuttons and E-stop GPIO. Posts manual command events to FSM event queue
HMI Display | 0 | 10 | 200 ms | Renders TFT screen: state name, deck height bar gauge (0–180 mm), motor current, sensor status icons, fault banner, mode indicator

5.3 System State Machine

The FSM governs all system transitions through a table of (current_state, event, guard_function, action_function, next_state) tuples. Guard functions return true only if all preconditions are met. Action functions execute the transition (e.g., setting motor direction, updating traffic lights). The ten system states and their key transitions are:

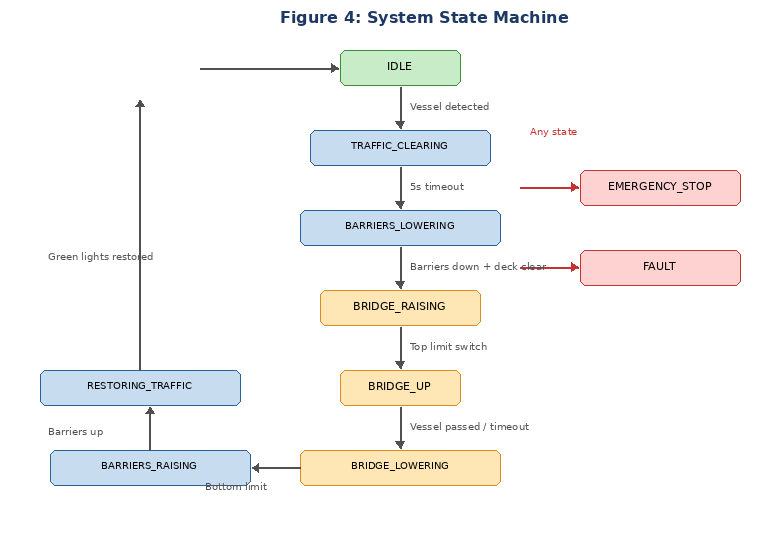
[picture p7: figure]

Figure 4: System state machine — ten states governing the complete bridge operation cycle

From State | Event | Guard | To State
IDLE | EVT_VESSEL_DETECTED | Auto mode, no faults, no E-stop | TRAFFIC_CLEARING
IDLE | EVT_MANUAL_RAISE | Manual mode, no faults, no E-stop | TRAFFIC_CLEARING
TRAFFIC_CLEARING | EVT_TIMEOUT (5 s) | Road signals are red | BARRIERS_LOWERING
BARRIERS_LOWERING | EVT_BARRIERS_DOWN | Both barriers at 90°, deck clear on both IR sensors for 2 s | BRIDGE_RAISING
BRIDGE_RAISING | EVT_LIMIT_TOP | Top limit switch activated | BRIDGE_UP
BRIDGE_UP | EVT_VESSEL_PASSED | Downstream dual-beam station triggered | BRIDGE_LOWERING
BRIDGE_UP | EVT_HOLD_TIMEOUT | 15-second fallback | BRIDGE_LOWERING
BRIDGE_LOWERING | EVT_LIMIT_BOTTOM | Bottom limit switch activated | BARRIERS_RAISING
BARRIERS_RAISING | EVT_BARRIERS_UP | Both barriers at 0° | RESTORING_TRAFFIC
RESTORING_TRAFFIC | EVT_TRAFFIC_OK | Road signals are green | IDLE
ANY STATE | EVT_ESTOP | Always accepted | EMERGENCY_STOP
ANY STATE | EVT_FAULT | Always accepted | FAULT

6. CUSTOM PRINTED CIRCUIT BOARD

The PCB is designed in KiCad 8 and fabricated by JLCPCB. Board dimensions: 100 mm × 80 mm, two-layer FR4 with HASL (Hot Air Solder Levelling) surface finish and green solder mask. The design uses a hierarchical schematic with six sub-sheets: (A) Power Supply, (B) ESP32 Module, (C) USB-UART Bridge, (D) Motor Driver, (E) Shift Register and LEDs, (F) Connectors and Safety.

Layout guidelines: The bottom copper layer (B.Cu) is a continuous ground plane for low-impedance return paths and EMI reduction. All signal traces are routed on the top layer (F.Cu). Signal traces are 0.5 mm (20 mil) minimum width. The 5 V power traces are 1.0 mm (40 mil). The 12 V and motor current traces are 1.5 mm (60 mil). The LM2596 switching regulator and its inductor/diode are placed as far as possible from the ESP32 antenna to minimise switching noise coupling. All IC decoupling capacitors are placed within 5 mm of their respective VCC pins. Four M3 mounting holes (3.2 mm diameter) are placed at the corners, 5 mm from the board edges, for securing the PCB to the base platform with nylon standoffs.

7. BILL OF MATERIALS

The following table lists every component required to build the complete system, including all components that will be soldered to the PCB. Prices are sourced from Nerokas (store.nerokas.co.ke), Pixel Electronics (pixelectronics.co.ke), and local Nairobi electronics shops on Luthuli Avenue. JLCPCB pricing includes DHL shipping to Nairobi.

7.1 PCB Components (soldered to board)

Item | Part Number | Qty | Unit Price (KES) | Total (KES) | Source
ESP32-WROOM-32 Module | ESP32-WROOM-32 | 1 | 850 | 850 | Nerokas
CP2102N USB-UART IC | CP2102N-A01 | 1 | 200 | 200 | ASK Electronics
DRV8871 Motor Driver | DRV8871DDAR | 1 | 350 | 350 | ASK Electronics
74HC595 Shift Register | SN74HC595N | 1 | 40 | 40 | Sagana / Luthuli Ave
LM2596-5.0 Buck Converter | LM2596S-5.0 | 1 | 120 | 120 | Nerokas
AMS1117-3.3 LDO | AMS1117-3.3 | 1 | 30 | 30 | Sagana / Luthuli Ave
330 µH Power Inductor | SRN8040-330M | 1 | 50 | 50 | Nerokas
1N5824 Schottky Diode (3A) | 1N5824 | 1 | 20 | 20 | Sagana / Luthuli Ave
SS34 Schottky Diode (polarity) | SS34 | 1 | 15 | 15 | Sagana / Luthuli Ave
1N4148 Signal Diode (flyback) | 1N4148 | 1 | 5 | 5 | Sagana / Luthuli Ave
2N3904 NPN Transistor | 2N3904 | 2 | 10 | 20 | Sagana / Luthuli Ave
2N7000 N-ch MOSFET | 2N7000 | 1 | 20 | 20 | Sagana / Luthuli Ave
USB Type-C Connector | USB-C 16-pin SMD | 1 | 60 | 60 | Nerokas
SRD-05VDC Relay | SRD-05VDC-SL-C | 1 | 100 | 100 | Nerokas
100 µF/25V Electrolytic Cap | Radial | 2 | 15 | 30 | Sagana / Luthuli Ave
220 µF/16V Electrolytic Cap | Radial | 1 | 15 | 15 | Sagana / Luthuli Ave
10 µF Tantalum Cap | SMD/TH | 2 | 25 | 50 | Sagana / Luthuli Ave
100 nF Ceramic Cap | MLCC 0805 | 10 | 3 | 30 | Sagana / Luthuli Ave
Resistors (various values) | 1/4W 1% | 30 | 2 | 60 | Sagana / Luthuli Ave
5 mm LED Red | Water clear | 4 | 5 | 20 | Sagana / Luthuli Ave
5 mm LED Yellow | Water clear | 2 | 5 | 10 | Sagana / Luthuli Ave
5 mm LED Green | Water clear | 4 | 5 | 20 | Sagana / Luthuli Ave
Barrel Jack 5.5×2.1 mm | PCB mount | 1 | 30 | 30 | Sagana / Luthuli Ave
2-pin Screw Terminal | 5.08 mm pitch | 2 | 15 | 30 | Sagana / Luthuli Ave
JST-XH 3-pin Header | 2.5 mm pitch | 6 | 10 | 60 | Nerokas
JST-XH 4-pin Header | 2.5 mm pitch | 4 | 12 | 48 | Nerokas
2×5 Pin Header (TFT) | 2.54 mm pitch | 1 | 10 | 10 | Sagana / Luthuli Ave
2×4 Pin Header (panel) | 2.54 mm pitch | 1 | 10 | 10 | Sagana / Luthuli Ave
Green Power LED | 3 mm | 1 | 5 | 5 | Sagana / Luthuli Ave
PCB Components Subtotal | | | | 2,308

7.2 Off-Board Electronic Components

Item | Part Number | Qty | Unit Price (KES) | Total (KES) | Source
HC-SR04 Ultrasonic Sensor | HC-SR04 | 4 | 350 | 1,400 | Nerokas
FC-51 IR Obstacle Sensor | FC-51 | 2 | 120 | 240 | Pixel Electronics
KW12-3 Microswitch | KW12-3 | 8 | 40 | 320 | Sagana / Luthuli Ave
10 kΩ Linear Potentiometer | B10K | 1 | 50 | 50 | Sagana / Luthuli Ave
SG90 Micro Servo | SG90 | 2 | 250 | 500 | Nerokas
Active Piezo Buzzer | 12 V | 1 | 50 | 50 | Sagana / Luthuli Ave
2.8″ ILI9341 TFT Display | SPI | 1 | 650 | 650 | Nerokas
Tactile Pushbuttons | 6×6 mm | 4 | 10 | 40 | Sagana / Luthuli Ave
E-Stop Latching Button | NC, red, 22 mm | 1 | 250 | 250 | Nerokas
SPDT Toggle Switch | ON-ON | 1 | 50 | 50 | Sagana / Luthuli Ave
12 V 3A DC Power Adapter | 5.5×2.1 mm plug | 1 | 500 | 500 | Nerokas
JGA25-370 Geared Motor 60RPM | 12 V DC | 1 | 450 | 450 | Nerokas
Off-Board Electronics Subtotal | | | | 4,500

7.3 Mechanical Components

Item | Description | Qty | Unit Price (KES) | Total (KES) | Source
T8 Lead Screw + Brass Nut | T8×8mm lead, 300 mm | 4 | 450 | 1,800 | Nerokas
GT2 Timing Belt (open) | 2 mm pitch, 6 mm wide, per metre | 3 | 350 | 1,050 | Nerokas
GT2 20T Pulley (5mm bore) | Aluminium, 20 teeth, 5 mm bore | 4 | 350 | 1,400 | K-Technics
GT2 Idler Pulley | Smooth, 5 mm bore (tensioner) | 2 | 200 | 400 | Nerokas
Shaft Bearings | 608ZZ, 8 mm bore | 8 | 80 | 640 | ASK Electronics
Aluminium Angle Rails | 10×10 mm, 300 mm | 8 | 100 | 800 | Sagana / Luthuli Ave
Plywood Base Platform | 900×600 mm, 12 mm | 1 | 400 | 400 | Sagana / Luthuli Ave
Plywood Tower Panels | 10 mm, 600×300 mm | 1 | 250 | 250 | Sagana / Luthuli Ave
Acrylic Sheet (deck) | 5 mm, A3 size | 1 | 400 | 400 | Pixel Electronics
L-Brackets, Bolts, Nuts Kit | M3/M4 assorted | 1 | 400 | 400 | ASK Electronics
M3 Nylon Standoffs (PCB) | 10 mm, M3 | 8 | 15 | 120 | Sagana / Luthuli Ave
Flexible Shaft Coupling | 5 mm to 8 mm | 1 | 150 | 150 | Nerokas
Mechanical Subtotal | | | | 7,810

7.4 Fabrication and Consumables

Item | Description | Qty | Unit Price (KES) | Total (KES) | Source
PCB Fabrication | JLCPCB, 5 boards, 2-layer, HASL, green | 1 order | 2,100 | 2,100 | JLCPCB (incl. DHL)
Solder Wire | 60/40, 0.8 mm, 50 g | 1 | 200 | 200 | Sagana / Luthuli Ave
Wire (hookup) | 22 AWG, assorted colours, 10 m | 1 | 150 | 150 | Sagana / Luthuli Ave
Heat Shrink Tubing | Assorted diameters | 1 pack | 100 | 100 | Sagana / Luthuli Ave
Cable Ties | 100 mm, 50 pack | 1 | 50 | 50 | Sagana / Luthuli Ave
Paint + Vinyl Tape | Grey, white, blue | 1 set | 100 | 100 | Sagana / Luthuli Ave
Fabrication Subtotal | | | | 2,700

Category | Cost (KES)
PCB Components (soldered) | 2,308
Off-Board Electronics | 4,500
Mechanical Components | 7,810
Fabrication and Consumables | 2,700
GRAND TOTAL | 17,318
PER MEMBER (5 members) | ~KES 3,464

8. PROPOSED BUILD TIMELINE

Phase | Week | Deliverable
1 | Week 1 | KiCad schematic complete (6 sub-sheets). PCB layout with DRC clean. Gerber files generated and JLCPCB order placed. BOM finalised and procurement from Nerokas, Pixel Electronics, and Luthuli Avenue started.
2 | Week 2 | pin_config.h and system_types.h committed to Git repository. FreeRTOS task skeleton with event queues and mutexes operational. All module header files (.h) published with agreed APIs. Mechanical base platform and tower construction begins.
3 | Week 3 | PCBs arrive from JLCPCB. Assembly in strict soldering sequence: SMD passives → AMS1117 (test 3.3 V) → LM2596 (test 5 V) → CP2102N (test USB COM port) → DRV8871 (test VPROPI) → 74HC595 (test LED shift) → ESP32 (test blink via USB) → connectors → relay + MOSFET. Each power rail tested with multimeter before soldering downstream components.
4 | Weeks 3–4 | Individual firmware modules developed and unit-tested: motor driver + potentiometer feedback, dual-beam ultrasonic sensor + direction algorithm, traffic light sequencing + servo barriers, TFT display rendering + button input, safety watchdog + fault register.
5 | Week 5 | Mechanical assembly complete: towers, guide rails, lead screws, GT2 belt and pulleys, deck, sensors, traffic lights, barriers, PCB — all mounted on base platform and wired to PCB via JST-XH connectors.
6 | Week 6 | Full system integration testing. FSM walk-through in both AUTO and MANUAL modes. All fault scenarios deliberately triggered: E-stop press, overcurrent (stall motor by hand), anti-jam (block guide rail), limit switch override, deck-occupied interlock. Pass criterion: 20 consecutive automatic cycles without fault.
7 | Week 7 | Parameter tuning: motor PWM speed, servo sweep rate, traffic light phase timing, ultrasonic detection threshold, hold timeout duration. System robustness hardening.
8 | Week 8 | Technical report writing, demonstration script, and presentation slides completed. Live demonstration to lecturer. Demo backup video recorded.

9. MICROPROCESSOR CONCEPTS DEMONSTRATED

The following EEE 2412 Microprocessors II course concepts are directly and demonstrably applied in this project:

Concept | Implementation in This Project
GPIO Control | Motor driver IN1/IN2, relay MOSFET gate, shift register data/clock/latch, servo signals, buzzer, traffic LEDs (via 74HC595), limit switches, E-stop, mode switch, and four pushbuttons — all managed through ESP32 GPIO pins configured as inputs or outputs.
ADC (Analogue-to-Digital Conversion) | ESP32 12-bit ADC reads DRV8871 VPROPI current-sense output (GPIO 36) and potentiometer deck-height feedback (GPIO 34) with 16-sample oversampling and averaging for noise rejection.
PWM (Pulse Width Modulation) | LEDC peripheral generates 20 kHz PWM on GPIO 25/26 for DRV8871 motor speed control (8-bit resolution, 0–255 duty), and 50 Hz PWM on GPIO 4/15 for SG90 servo position (500–2400 µs pulse width).
Interrupt-Driven I/O | Limit switch triggers use GPIO interrupts (FALLING edge) for deterministic sub-millisecond motor cutoff independent of the task scheduler. E-stop detection uses a GPIO interrupt. Ultrasonic echo timing uses hardware timer capture.
SPI Communication | The 74HC595 shift register and ILI9341 TFT display share the SPI bus (GPIO 23 MOSI, GPIO 18 SCLK) with separate chip select lines (GPIO 0 for latch, GPIO 15 for TFT CS). A FreeRTOS mutex prevents simultaneous bus access.
Timer Peripherals | FreeRTOS tick timer (1 ms), LEDC PWM timer channels, ultrasonic echo measurement using esp_timer, traffic light phase timers using xTimerCreate, and debounce timers for pushbuttons.
RTOS / Multitasking | FreeRTOS manages seven concurrent tasks with priority scheduling across dual cores (Core 0 and Core 1), mutex-protected shared state (SharedStatus_t), and inter-task event queues (xQueueSend/xQueueReceive).
State Machine Design | Ten-state finite state machine implemented as a table of transition structures. Each entry contains: current_state, event, guard_function_pointer, action_function_pointer, next_state. The FSM engine iterates the table every 10 ms.
Non-Volatile Memory | Potentiometer calibration endpoints (ADC values at deck bottom and top), ultrasonic detection threshold, and overcurrent threshold are stored in ESP32 NVS (Non-Volatile Storage) partition, persistent across power cycles.
Watchdog Timer | FreeRTOS Task Watchdog Timer (TWDT) monitors the safety watchdog task. If the task fails to call esp_task_wdt_reset() within 500 ms (indicating a task hang or crash), the ESP32 triggers a hardware reset, ensuring fail-safe behaviour.

10. GROUP ROLE ALLOCATION

Task allocations will be formally agreed upon by the group following lecturer approval of this proposal. Indicative responsibilities are listed below as a working framework:

Role | Responsibilities | Member
Firmware Lead (Member 1) | FreeRTOS architecture, FSM engine, pin_config.h, system_types.h, event queues and mutexes, boot sequence, main.cpp, system integration lead. | TBD
Mechanism Lead (Member 2) | Tower and deck construction, motor mounting, GT2 timing belt and pulley assembly, lead screw installation, guide rail alignment, potentiometer calibration, limit switch positioning. | TBD
Sensors Lead (Member 3) | Dual-beam HC-SR04 driver code, direction-determination algorithm, FC-51 IR sensor integration, generic debounce engine, sensor calibration, event generation. | TBD
HMI Lead (Member 4) | 74HC595 LED shift-out driver, traffic light phase sequencing, servo barrier sweep code, buzzer alarm patterns, TFT display rendering (TFT_eSPI), button input debounce and event posting. | TBD
PCB and Safety Lead (Member 5) | KiCad schematic and PCB layout design, Gerber generation, JLCPCB order, power supply design, E-stop relay circuit, safety watchdog firmware, fault register, BOM management, PCB assembly lead. | TBD

11. CONCLUSION

The Automatic Vertical Lift Bridge Control System fully satisfies the requirements of the EEE 2412 Microprocessors II project. It provides a complete, physically operational scale-model bridge with automated directional vessel detection, mechanically synchronised four-point vertical lift, sequenced traffic management, comprehensive safety interlocks, and a local TFT-based Human Machine Interface—all governed by an ESP32 running FreeRTOS with seven concurrent tasks.

The mechanically-linked four-screw drive system, using a GT2 timing belt loop and four pulleys driven by a single motor, eliminates electronic synchronisation complexity while guaranteeing perfectly level deck travel. The dual-beam directional sensing system at each end of the waterway correctly identifies vessel heading, handles simultaneous bidirectional traffic, and rejects false triggers from noise or debris—capabilities absent from conventional single-sensor designs.

The project applies the full breadth of the Microprocessors II curriculum: GPIO control, analogue-to-digital conversion, pulse width modulation, interrupt-driven I/O, SPI serial communication, hardware timer peripherals, FreeRTOS real-time multitasking, finite state machine design, non-volatile memory persistence, and watchdog timer implementation. The custom PCB designed in KiCad and fabricated by JLCPCB demonstrates circuit design, layout, and integration skills beyond firmware alone.

The total component budget of approximately KES 17,318 (approximately KES 3,464 per member) is achievable within the group’s means. The eight-week build timeline is realistic given the five parallel workstreams enabled by the member role allocation.

Group 5 respectfully requests the approval of this proposal to proceed to the implementation phase.

Submitted by: Group 5

Date: April 2026

____________________________________________

Lecturer Signature & Date of Approval

Automatic Vertical Lift Bridge Control System | Page 1 of 2

EEE 2412 — Microprocessors II | Project Proposal | Group 5 | JKUAT

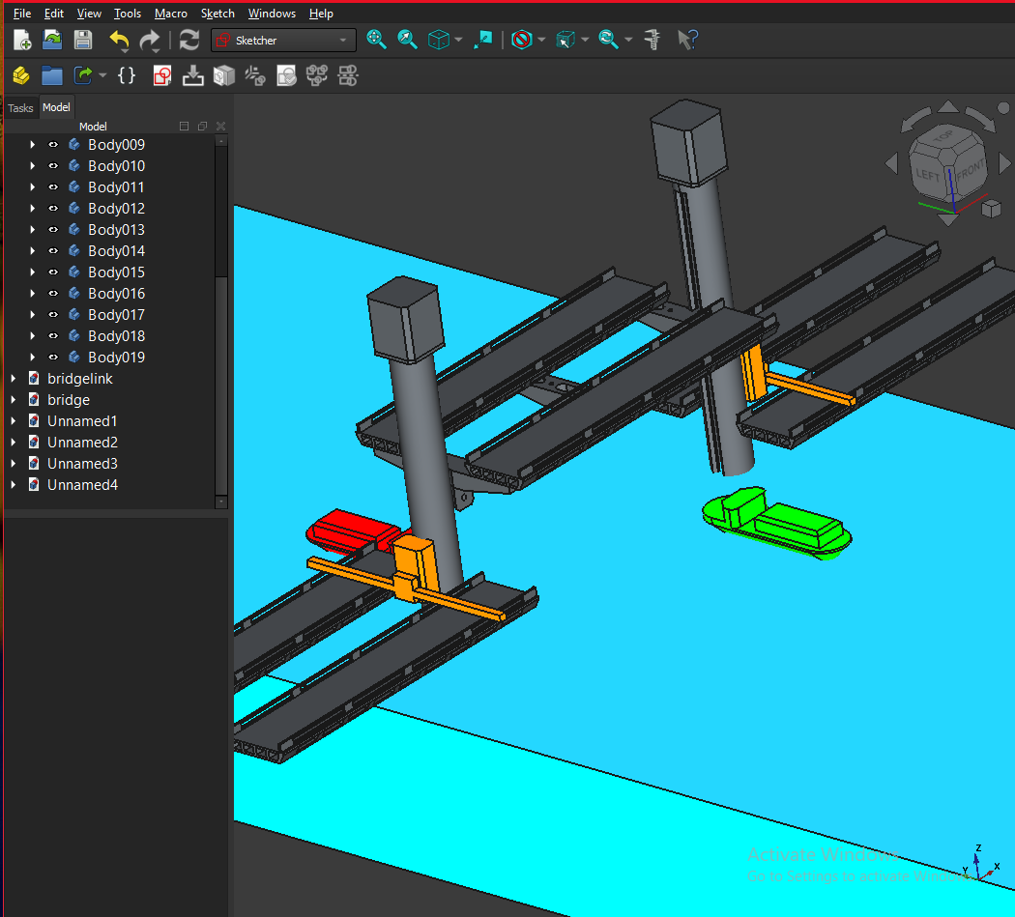
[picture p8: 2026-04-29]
mechanical/photos/Screenshot (91).png

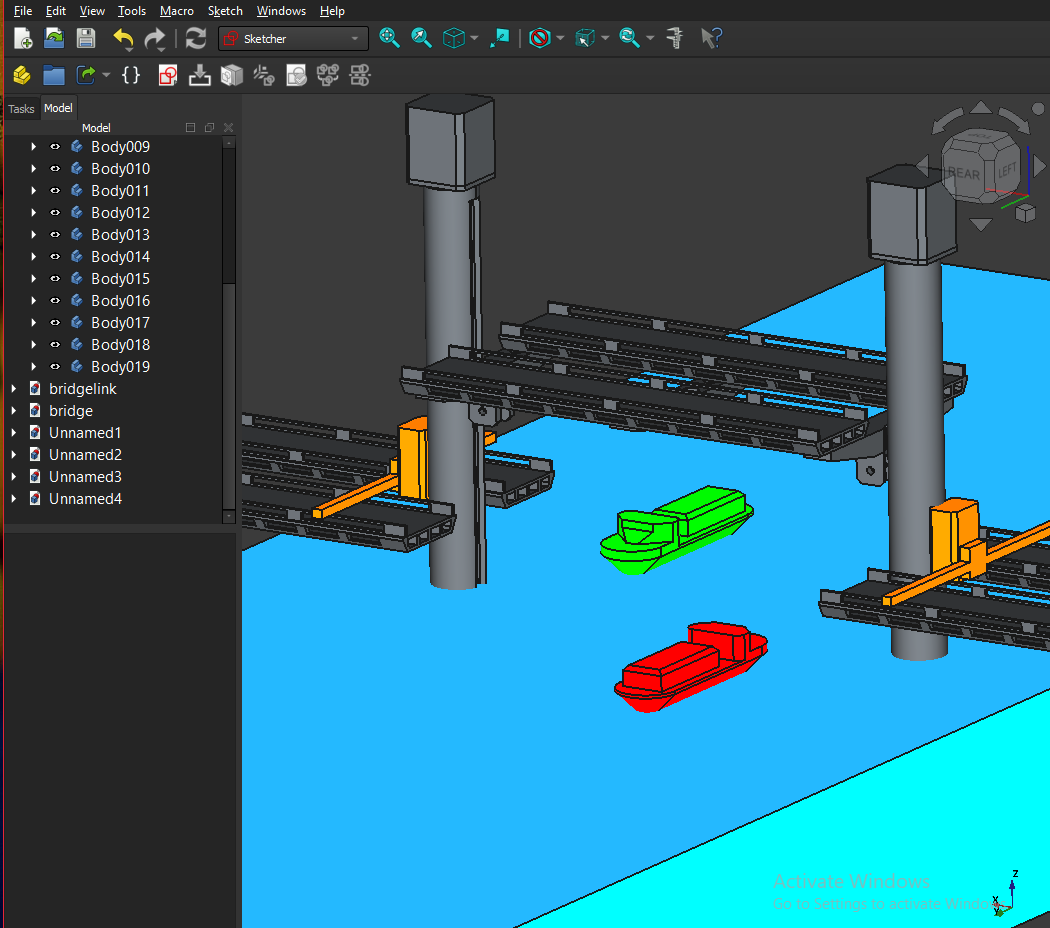
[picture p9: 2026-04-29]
mechanical/photos/Screenshot (92).png

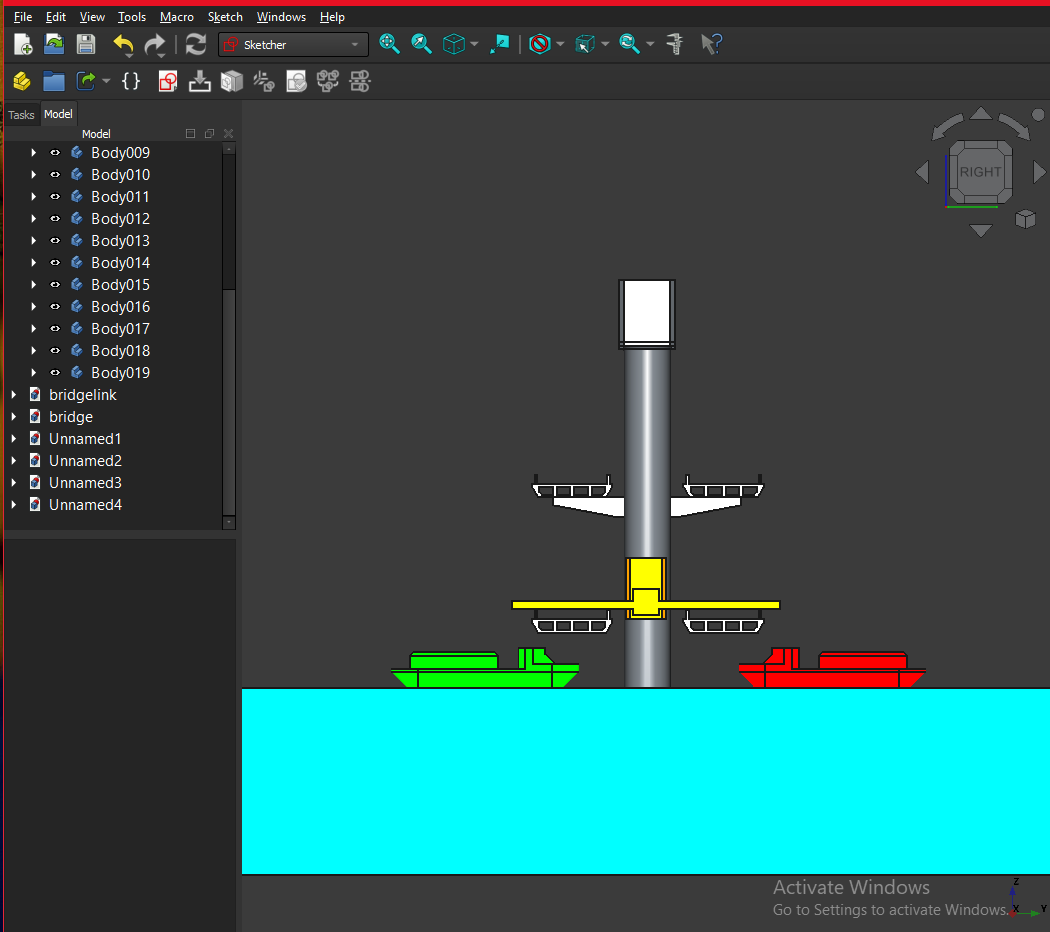
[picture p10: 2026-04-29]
mechanical/photos/Screenshot (94).png

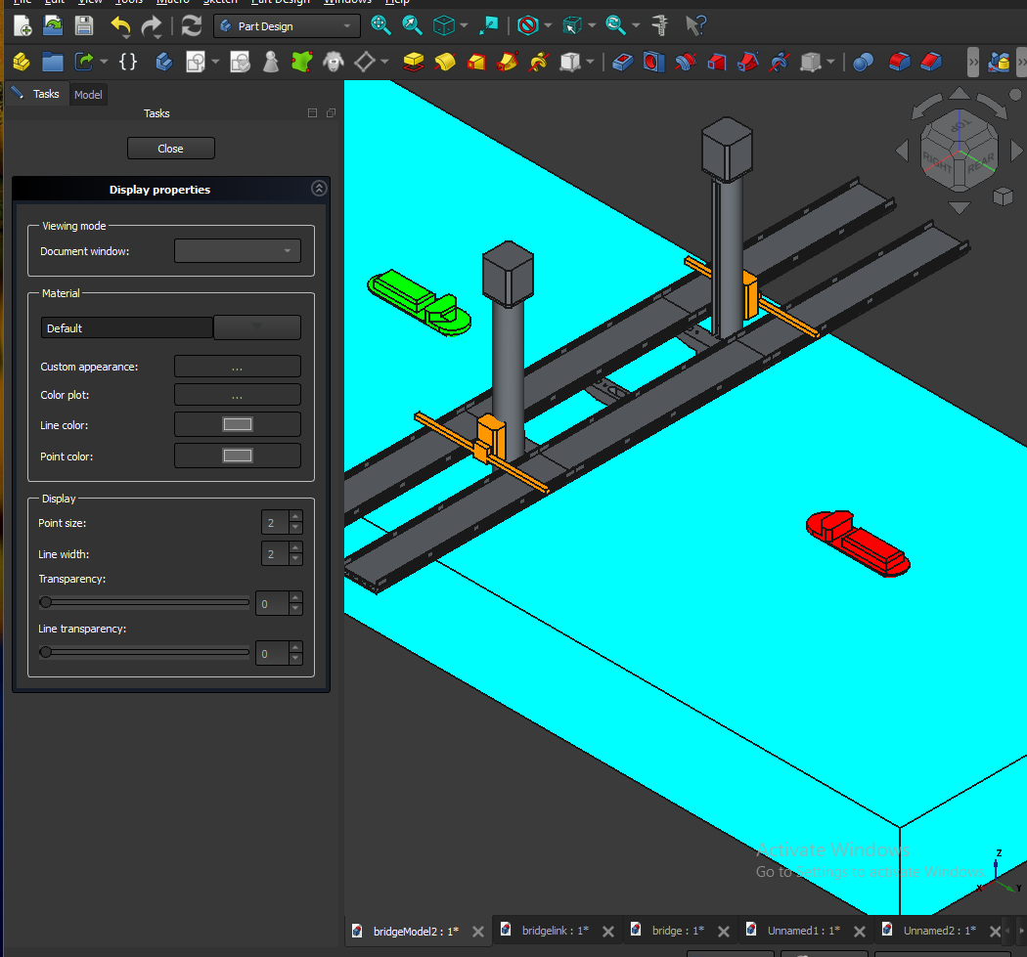
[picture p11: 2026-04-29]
mechanical/photos/Screenshot (86).png

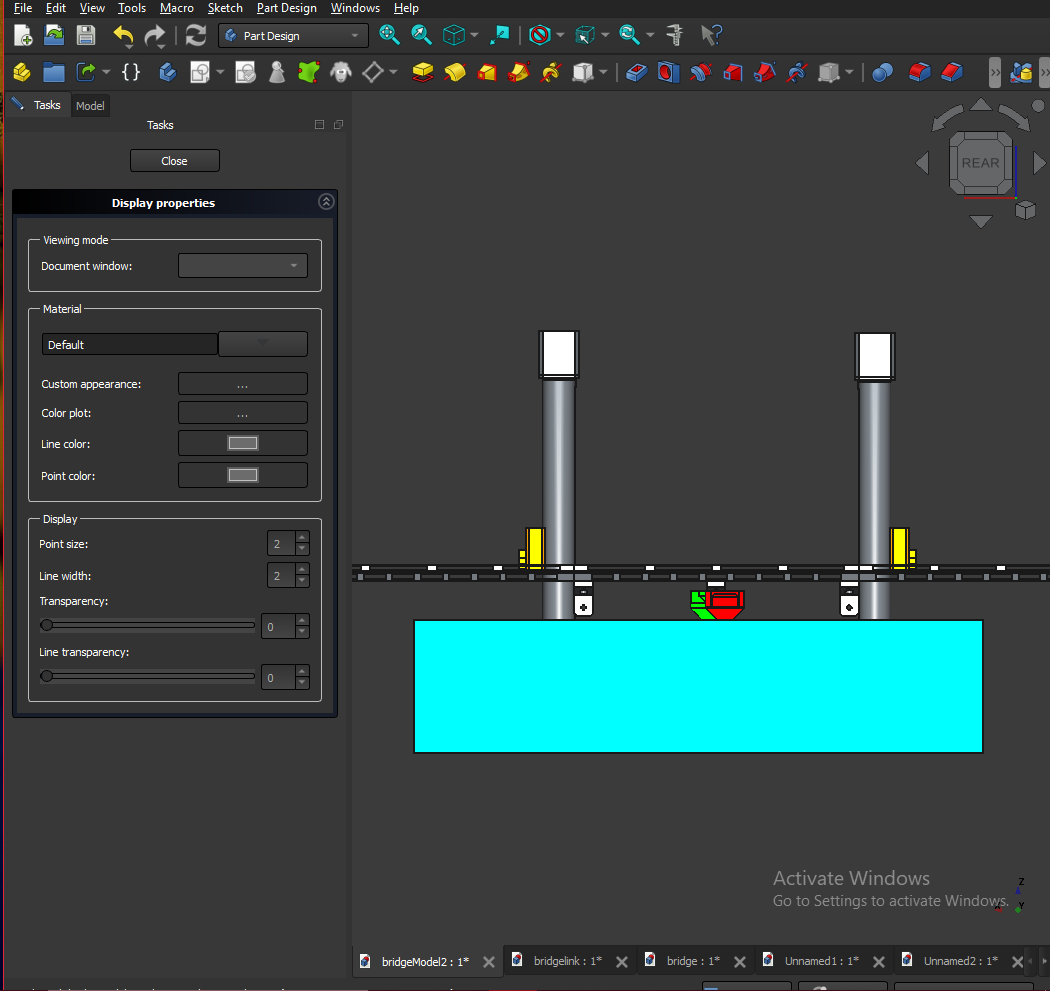
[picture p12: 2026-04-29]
mechanical/photos/Screenshot (88).png

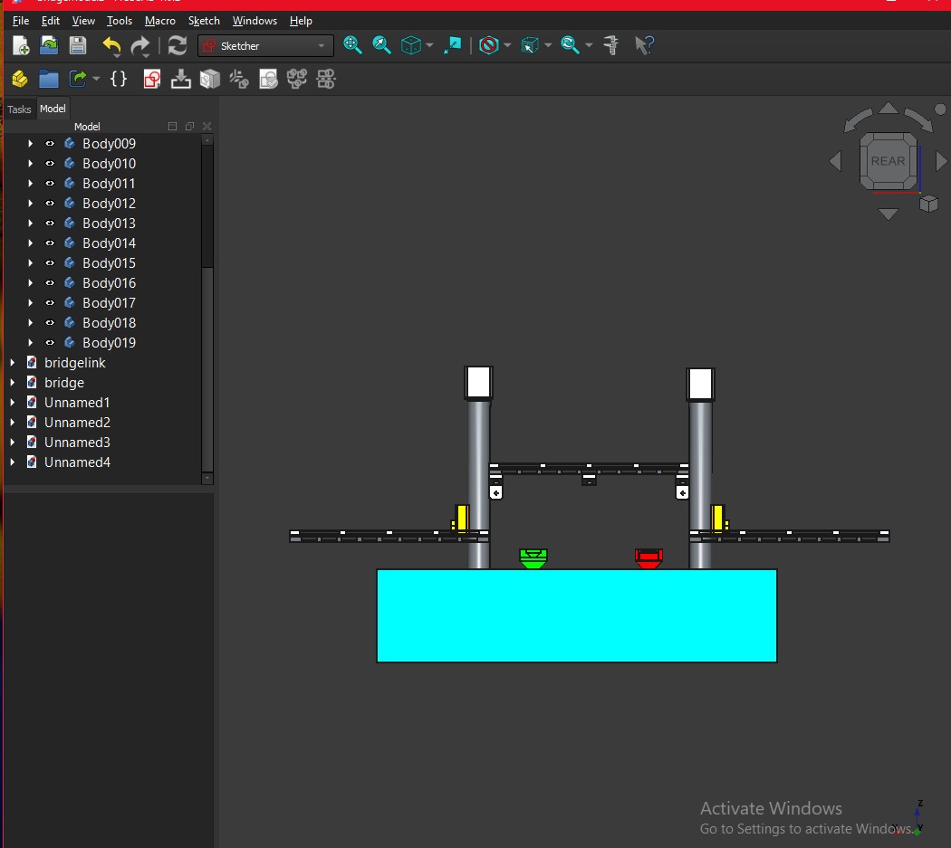
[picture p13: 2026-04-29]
mechanical/photos/Screenshot (93).png

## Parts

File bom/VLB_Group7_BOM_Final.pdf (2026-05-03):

# | Item | Part / Spec | Supplier | Unit (KES) | Qty | Total (KES) | Justification / Notes

1 | JGA25-370 12V DC gearmotor 100 RPM Hall encoder | JGA25-370 100RPM | K-Technics | 1,300 | 1 | 1,300 | Main lift drive — 4.0 kg·cm enough for 175 mm deck + 2× counterweight
2 | Aluminium spool/drum Ø30 mm × 25 mm | Custom (Sagana machine shop) | Sagana | 600 | 1 | 600 | Cable wrap drum — keyed to motor 6 mm shaft
3 | Braided steel cable Ø1.0 mm (3 m) | 1mm 7×7 braided | Luthuli | 350 | 1 | 350 | 2× 1 m cables for counterweights + 0.5 m spares
4 | Pulley wheel groove Ø50 mm (3D printed) | PLA — see CAD | In-house print | - | 4 | - | Top of each tower — 2 left + 2 right
5 | 608 ZZ skate bearing (8×22×7) | 608ZZ | Pixel | 50 | 8 | 400 | Pulley axles + drum bearings
6 | Lead fishing weight 60 g (counterweight fill) | Strip — bulk | Luthuli | 80 | 4 | 320 | 2× 120 g counterweights = 4× 60 g pieces
7 | MGN12 linear rail 200 mm + carriage | MGN12-200 set | Nerokas | 1,250 | 2 | 2,500 | Bridge deck guides — 1 per tower
8 | SG90 micro servo (barrier arms) | SG90 9g | pixel | 300 | 2 | 600 | Two road barrier servos
9 | HC-SR04 ultrasonic module | HC-SR04 | Nerokas | 180 | 4 | 720 | Dual beam direction inference
10 | ESP32-CAM AI-Thinker (vehicle vision) | ESP32-CAM OV2640 | Nerokas | 1,500 | 1 | 1,500 | Frame-difference vehicle detection on UART2
11 | Limit switch microswitch SPDT | KW11-3Z lever | Pixel | 80 | 4 | 320 | Top + bottom limit per tower (2 + 2 redundant)
12 | 3D-print PLA filament 1 kg (white + grey) | PLA generic | Pixel | 3,700 | 1 | 3,700 | All printed parts + spares
13 | Brass M3 thread insert (knurled) | M3 heat-set | Nerokas | 12 | 50 | 600 | PCB stand-offs, panels, motor mount
14 | M3×8 socket cap screws (pack) | M3×8 | Luthuli | 10 | 30 | 300 | General assembly
15 | M3×16 socket cap screws (pack) | M3×16 | Luthuli | 12 | 20 | 240 | Through-mount for towers
16 | M8×80 mm bolt + nut (pulley axle) | M8×80 | Luthuli | 60 | 2 | 120 | Top-pulley axles
17 | Aluminium L-bracket 25×25×3 mm × 1 m | L-stock | Luthuli | 350 | 1 | 350 | Tower base reinforcement
18 | MDF / plywood base 1200×600×12 mm | MDF 12 mm | Sagana | 800 | 1 | 800 | Project footprint base — printed panels overlay
| Subtotal — MECHANICAL | | | | | 14,720
1 | ESP32-WROOM-32E module (38-pin DevKit) | ESP32-WROOM-32E | Nerokas | 900 | 1 | 900 | Main controller
2 | L293L H-bridge driver module-48W,2A | MOTOR driver | K-Technics | 500 | 1 | 500 | Motor driver — overspec'd for safety margin
3 | AMS1117-3.3 LDO regulator | AMS1117-3.3 SOT-223 | Pixel | 15 | 3 | 45 | 3.3 V rail (1 used, 2 spare)
4 | LM1084 step-down buck module 12→5 V | LM1084-5V, 5A | Pixel | 150 | 1 | 150 | 5 V rail for servos + ESP32-CAM
5 | 12 V / 3 A DC barrel adapter | 5.5×2.1 mm DC | Pixel | 30 | 1 | 30 | Primary supply
6 | DC barrel jack 5.5×2.1 mm panel mount | DCJ0202 | Pixel | 30 | 1 | 30 | Power input on PCB
7 | DC-DC Schottky 5 A SS54 | SS54 | Pixel | 5 | 2 | 10 | Reverse-polarity protection
8 | Polyfuse PTC 2 A hold (12 V rail) | RXEF200 | Pixel | 40 | 1 | 40 | Resettable fuse on 12 V input
9 | TVS diode SMBJ15CA (transient on 12 V) | SMBJ15CA | Pixel | 35 | 1 | 35 | Surge protection
10 | ULN2803 (backlight + buzzer)-is 8 channel share with relays below | ULN2803 | Pixel | 50 | 1 | 50 | Logic-level switches
11 | ULN2803 (relay coil drive) | ULN2803 | Pixel | 50 | 1 | 50 | Low-side switch for relay
12 | SRD-05VDC-SL-C 5 V relay (E-stop chain) | SRD-05VDC-SL-C | Pixel | 50 | 1 | 50 | Motor power kill
13 | 74HC595 8-bit shift register (DIP-16) | 74HC595 | Pixel | 30 | 2 | 60 | Traffic-light LED chain (1 + 1 spare)
14 | XPT2046 + ILI9341 2.8" 240×320 TFT touch | TJCTM24028-SPI | ASK | 1,800 | 1 | 1,800 | Operator dashboard — TN panel
15 | Passive piezo buzzer 12 mm | Generic 12 mm | Pixel | 50 | 1 | 50 | Alarm + chirp

MECHANICAL

ELECTRONICS — PCB COMPONENTS, TFT, CAM

16 | Mushroom E-stop NC switch (panel) | 16 mm NC mushroom | Nerokas | 320 | 1 | 320 | Hard safety stop
17 | Tactile push-button 6×6 mm (panel) | 6×6×5 mm | Pixel | 8 | 6 | 48 | Front-panel resistor-ladder buttons
18 | Resistor ladder kit 1 kΩ × 5 (1 % 0805) | 1 kΩ 1 % 0805 | Pixel | 5 | 10 | 50 | Button ladder + voltage dividers
19 | 0805 resistor assortment kit | Yageo 0805 | Pixel | 5 | 25 | 125 | All passive resistors
20 | 0805 / SMD-A capacitor assortment | 100 nF / 10 µF / 100 µF | Pixel | 5 | 25 | 125 | Decoupling + bulk caps
21 | LED 0805 R/Y/G traffic chain | 0805 SMD LED | Pixel | 5 | 12 | 60 | 6× road + 6× marine + spares
22 | JST-XH 4-pin connector + crimp pins | JST-XH 2.54 | Pixel | 30 | 4 | 120 | TFT, CAM, sensor harnesses
23 | USB-UART CH340G module (programming header) | CH340G | Pixel | 350 | 1 | 350 | Backup programmer — DevKit has built-in
| Subtotal — ELECTRONICS — PCB COMPONENTS, TFT, CAM | | | | | 4,998
1 | PCB fab 100×80 mm 2-layer FR4 HASL-LF (qty 5) | JLCPCB / PCBWay | Online (DHL) | 1,900 | 1 | 1,900 | Includes shipping to KE — ~1.6 mm, matte black mask
2 | Stencil 100×80 mm framed | JLCPCB stencil | Online | 700 | 1 | 700 | Optional but speeds reflow
3 | Solder paste Sn63/Pb37 35 g (no-clean) | Mechanic 35 g | Pixel | 600 | 1 | 600 | For SMD reflow
4 | 0.6 mm leaded solder wire 100 g | 60/40 | Pixel | 350 | 1 | 350 | Through-hole + rework
5 | Flux pen / paste no-clean | AMTECH 559 | Pixel | 280 | 1 | 280 | Rework aid
6 | Isopropyl alcohol 250 mL 99 % | IPA | ASK | 280 | 1 | 280 | Board cleaning
| Subtotal — PCB FABRICATION & ASSEMBLY | | | | | 4,110
1 | Heat-shrink tubing assortment | 1.5–6 mm pack | Luthuli | 250 | 1 | 250 | Wire termination
2 | Hookup wire 22 AWG silicone (3 colors) | 22AWG silicone | Pixel | 350 | 1 | 350 | Power harness — 5 m total
3 | Hookup wire 26 AWG ribbon | 26AWG ribbon | Pixel | 250 | 1 | 250 | Signal harness
4 | Cable ties 100 mm + 200 mm | Mixed pack | Luthuli | 120 | 1 | 120 | Routing
5 | Hot-melt glue stick 7 mm × 30 | EVA glue stick | Luthuli | 180 | 1 | 180 | Print joining + strain relief
6 | Project enclosure ABS 150×100×60 mm | Generic ABS | Pixel | 450 | 1 | 450 | Backup if 3D-printed enclosure fails
7 | Acrylic 3 mm × A4 (deck overlay decals) | 3 mm clear | Luthuli | 250 | 1 | 250 | Deck markings overlay
| Subtotal — CONSUMABLES & MISC | | | | | 1,850
GRAND TOTAL (KES) | 25,678

Notes:

PCB FABRICATION & ASSEMBLY

CONSUMABLES & MISC

All prices in Kenyan Shillings (KES), VAT-inclusive where applicable.
Supplier shorthand: Nerokas (Nerokas Cyber Systems, Nairobi); Pixel (Pixel Electric, Luthuli Avenue); ASK (ASK Electronics, Tom Mboya); K-Technics (online KE); Luthuli/Sagana (street suppliers).
PCB fab quoted JLCPCB 5pcs 100×80 mm 2-layer + DHL ~7 days to Nairobi (≈ KES 1,900 all-in). Counterweights: 4× 60 g lead = 240 g total -> 120 g per side, balances 240 g deck assy with 1.0× SF. Lead unit: BLUE = manually entered input; BLACK = formula. Adjust E:F cells to scale procurement.

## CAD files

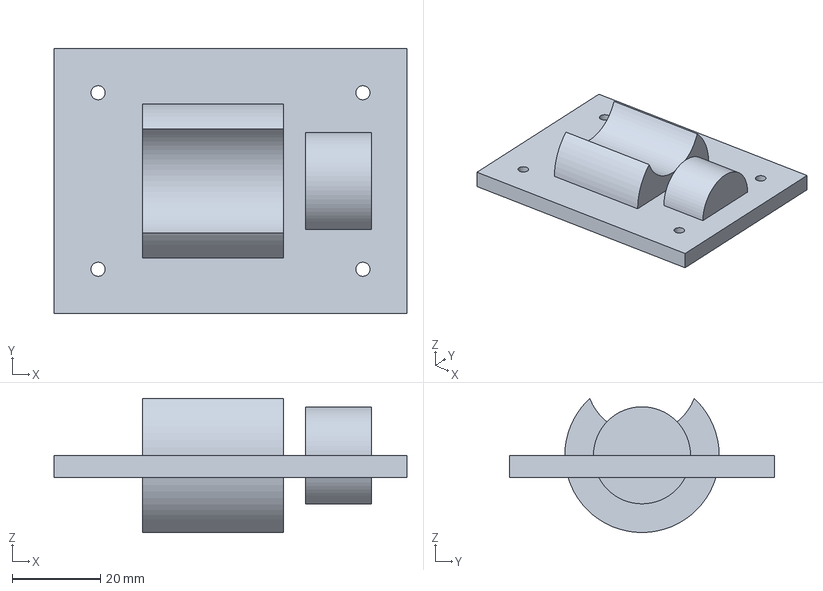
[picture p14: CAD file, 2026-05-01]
cad/step/07_motor_mount.3mf
80.0 x 60.0 x 30.4 mm

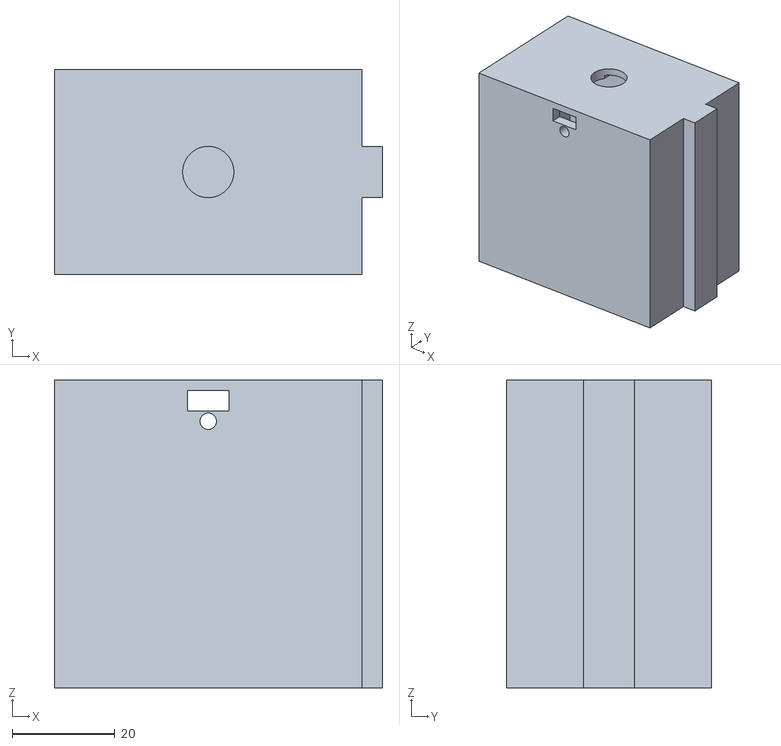
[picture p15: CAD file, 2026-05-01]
cad/stl/04_counterweight_left.stl
64.0 x 40.0 x 60.0

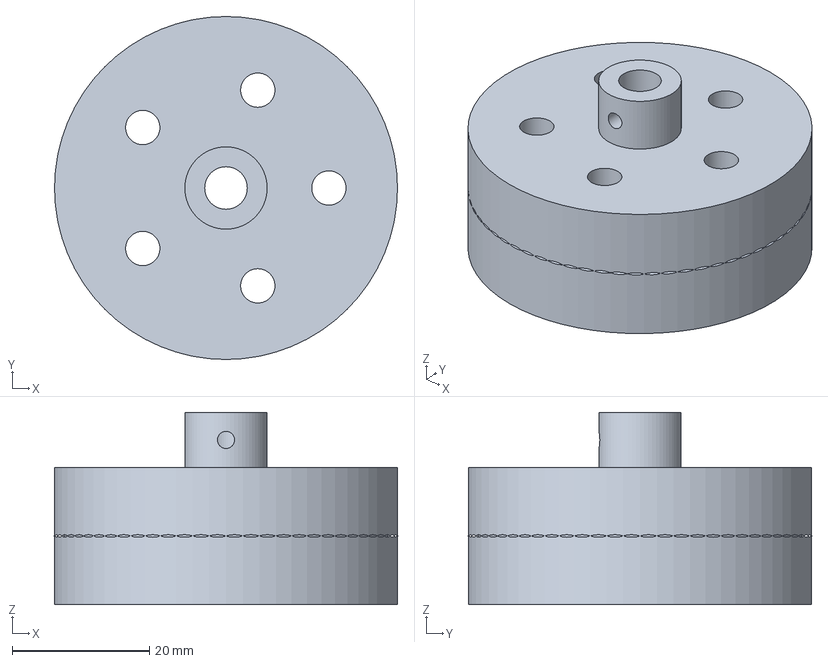
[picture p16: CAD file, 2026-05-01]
cad/step/06_pulley_wheel.3mf
50.0 x 50.0 x 28.0 mm

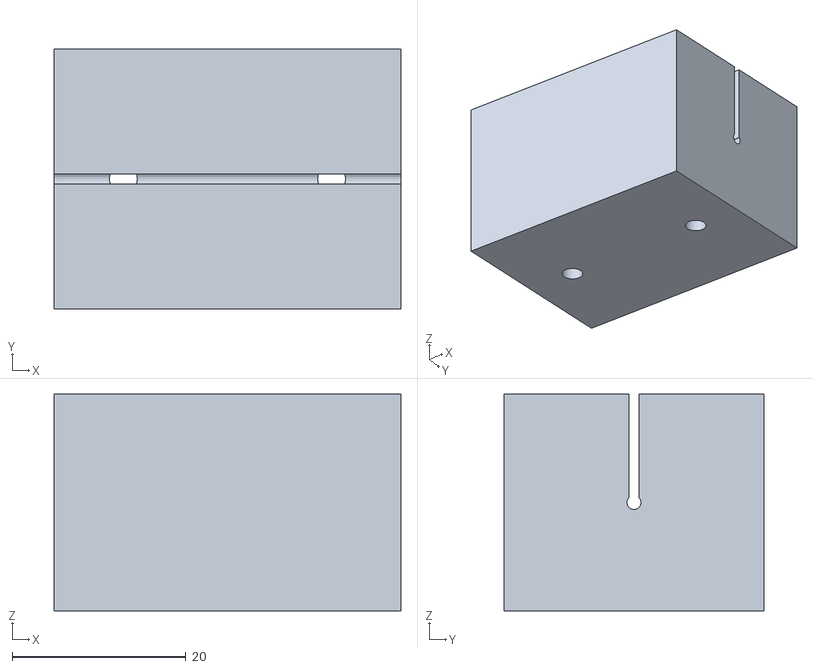
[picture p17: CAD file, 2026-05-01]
cad/stl/08_cable_guide.stl
40.0 x 30.0 x 25.0

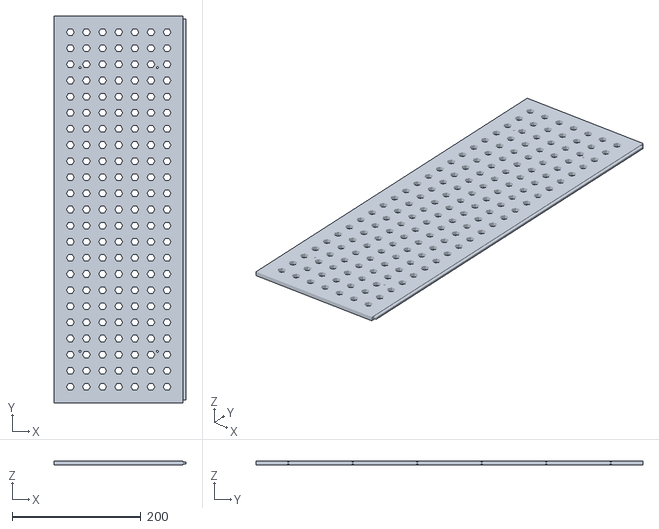
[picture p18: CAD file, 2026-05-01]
cad/stl/10_base_plate_section.stl
204.0 x 600.0 x 6.00

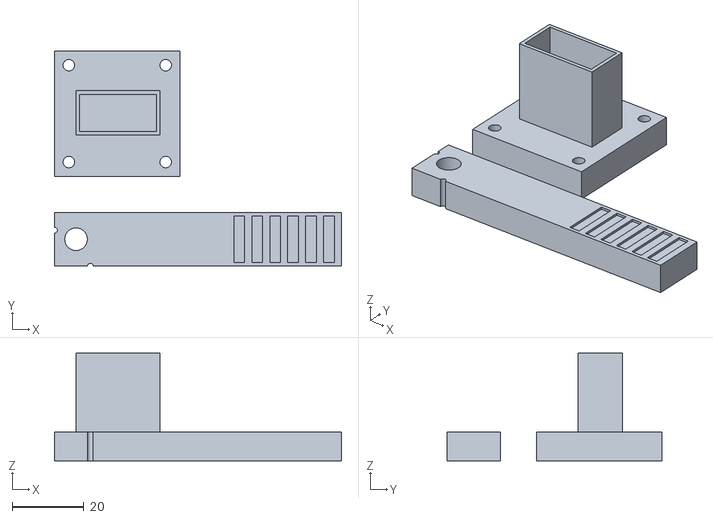
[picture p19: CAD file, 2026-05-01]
cad/stl/09_road_barrier.stl
80.0 x 60.0 x 30.0

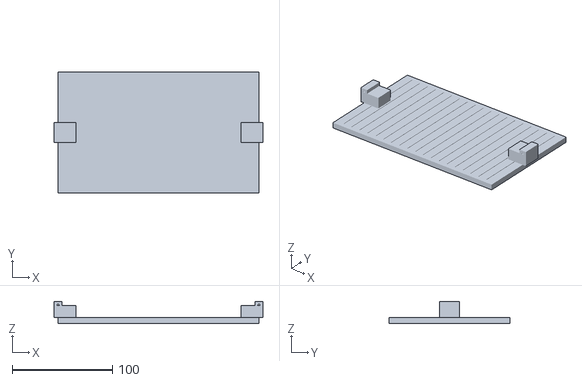
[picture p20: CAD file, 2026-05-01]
cad/stl/03_bridge_deck_section.stl
208.0 x 120.0 x 22.0

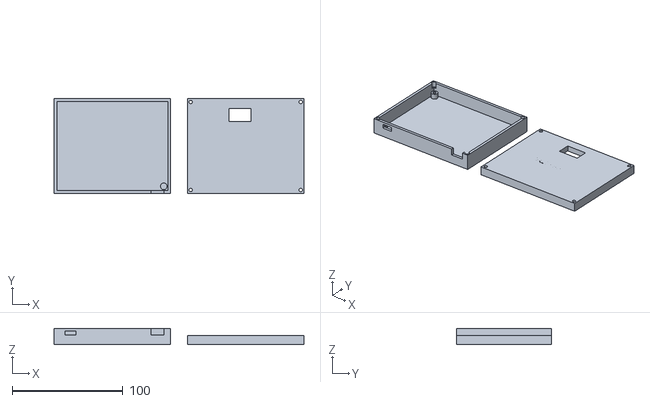
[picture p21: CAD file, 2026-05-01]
cad/stl/11_pcb_enclosure.stl
226.2 x 85.6 x 14.6

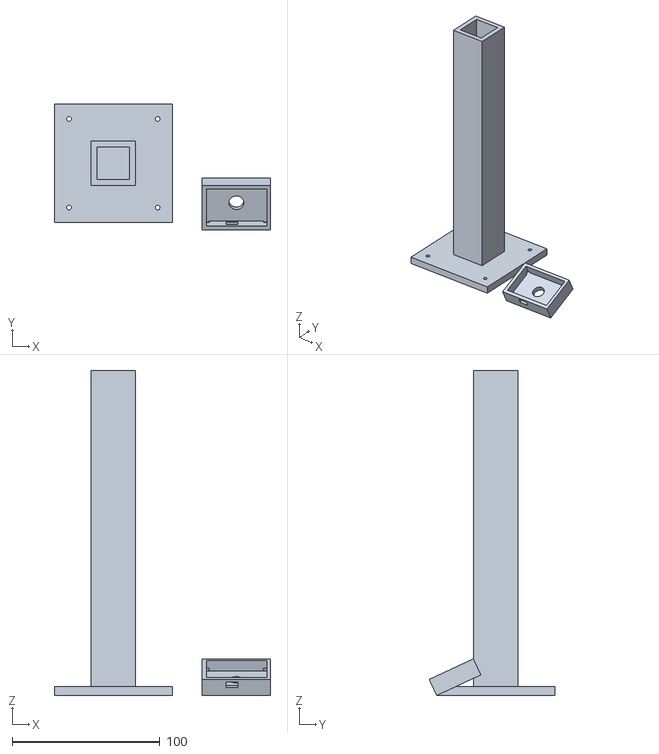
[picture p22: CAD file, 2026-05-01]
cad/stl/12_camera_mount.stl
146.5 x 85.1 x 220.0

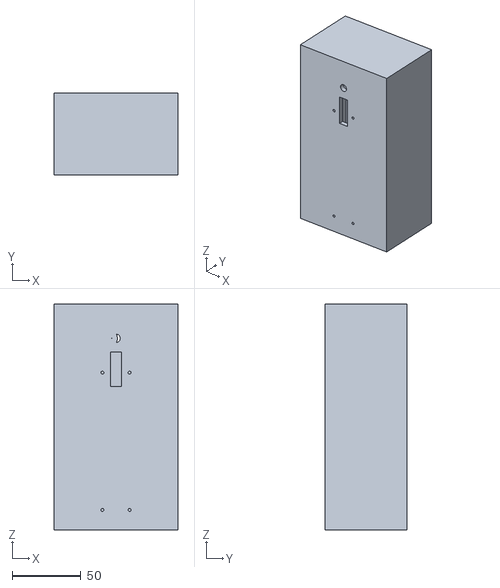
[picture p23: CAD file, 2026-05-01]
cad/stl/02_tower_right.stl
90.0 x 60.0 x 164.6

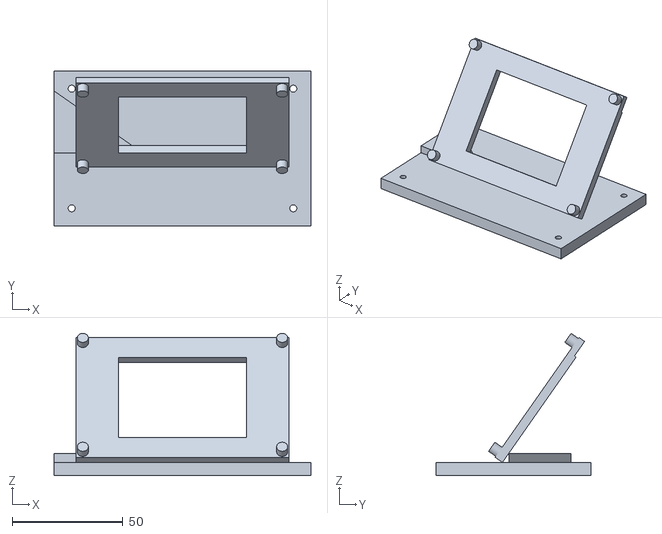
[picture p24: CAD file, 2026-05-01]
cad/stl/13_tft_display_mount.stl
116.0 x 70.0 x 64.2

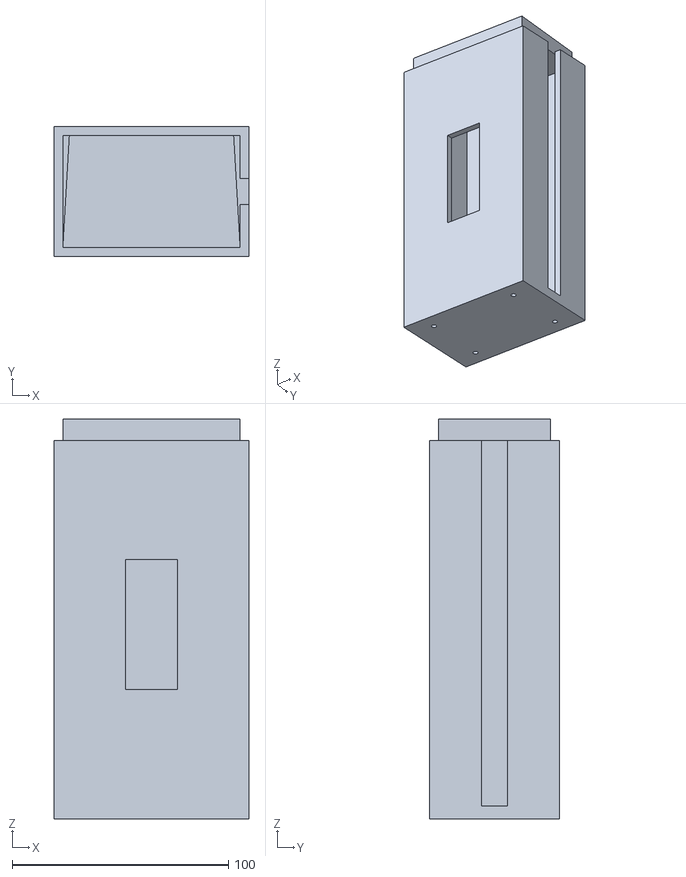
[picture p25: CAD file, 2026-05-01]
cad/stl/01_tower_left.stl
90.0 x 60.0 x 185.0

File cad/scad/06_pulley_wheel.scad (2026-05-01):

// 06_pulley_wheel.scad — Ø50 mm cable pulley with 1.4 mm groove
include <00_common.scad>

module pulley() {
    difference() {
        union() {
            // main body
            cylinder(d=PULLEY_D, h=PULLEY_W);
            // hub
            translate([0,0,PULLEY_W])
                cylinder(d=PULLEY_HUB_D, h=PULLEY_HUB_H);
        }
        // bore
        translate([0,0,-0.1])
            cylinder(d=PULLEY_BORE, h=PULLEY_W + PULLEY_HUB_H + 0.2);
        // groove
        translate([0,0,PULLEY_W/2])
            rotate_extrude($fn=128)
                translate([PULLEY_D/2 - PULLEY_GROOVE_D/2, 0, 0])
                    circle(d=PULLEY_GROOVE_D, $fn=32);
        // hub set-screw
        translate([0, 0, PULLEY_W + PULLEY_HUB_H/2])
            rotate([90,0,0])
                cylinder(d=2.5, h=PULLEY_HUB_D);
        // weight-reduction holes (5×)
        for (a = [0:72:359])
            rotate([0,0,a])
                translate([15, 0, -0.1])
                    cylinder(d=5, h=PULLEY_W + 0.2);
    }
}

pulley();

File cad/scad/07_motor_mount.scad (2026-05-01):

// 07_motor_mount.scad — JGA25-370 mount with cable-drum bearing block
include <00_common.scad>

module motor_mount() {
    PLATE_X = 80;
    PLATE_Y = 60;
    PLATE_T = 5;

    difference() {
        union() {
            // base plate
            cube([PLATE_X, PLATE_Y, PLATE_T]);
            // motor cradle (full height of motor body)
            translate([20, PLATE_Y/2, PLATE_T])
                rotate([0,90,0])
                    cylinder(d=MOTOR_BODY_D + 2*MOTOR_MOUNT_T,
                             h=MOTOR_BODY_L);
            // drum bearing pillar
            translate([20 + MOTOR_BODY_L + 5, PLATE_Y/2, PLATE_T])
                rotate([0,90,0])
                    cylinder(d=22, h=15);
        }
        // motor body bore (subtract)
        translate([20 - 0.1, PLATE_Y/2, PLATE_T + (MOTOR_BODY_D + 2*MOTOR_MOUNT_T)/2])
            rotate([0,90,0])
                cylinder(d=MOTOR_BODY_D + 0.4, h=MOTOR_BODY_L + 0.2);
        // shaft pass-through
        translate([20 + MOTOR_BODY_L - 0.1, PLATE_Y/2,
                   PLATE_T + (MOTOR_BODY_D + 2*MOTOR_MOUNT_T)/2])
            rotate([0,90,0])
                cylinder(d=MOTOR_SHAFT_D + 4, h=25);
        // drum bearing bore
        translate([20 + MOTOR_BODY_L + 5 - 0.1, PLATE_Y/2,
                   PLATE_T + (MOTOR_BODY_D + 2*MOTOR_MOUNT_T)/2])
            rotate([0,90,0])
                cylinder(d=MOTOR_SHAFT_D + 0.6, h=15.2);
        // baseplate fastener holes (4× M3)
        for (x = [10, PLATE_X-10], y = [10, PLATE_Y-10])
            translate([x, y, -0.1])
                cylinder(d=M3_CLEAR, h=PLATE_T + 0.2);
    }
}

motor_mount();

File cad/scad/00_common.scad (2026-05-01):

// vertical-lift-bridge :: COMMON PARAMETERS
// All dimensions in millimetres. Imported by every part file.
// Ratified parameters from audit Q1–Q7. Do not edit without group approval.

// ==== BUILD VOLUME ====
PRINTER_X = 220;
PRINTER_Y = 220;
PRINTER_Z = 250;
$fn = 64;  // smoothness for production prints

// ==== OVERALL FOOTPRINT ====
FOOTPRINT_X = 1200;        // along the road / cable axis
FOOTPRINT_Y = 600;         // across the river
BASE_T      = 6;           // base panel thickness
WATERWAY_W  = 200;         // navigable channel width

// ==== TOWERS ====
TOWER_H        = 350;       // total height (split-printed in 2 sections)
TOWER_SPLIT    = 175;       // join height
TOWER_W        = 90;        // width
TOWER_D        = 60;        // depth
TOWER_WALL     = 4;         // wall thickness
TOWER_INNER_W  = TOWER_W - 2*TOWER_WALL;
TOWER_INNER_D  = TOWER_D - 2*TOWER_WALL;
TOWER_SPACING  = 800;       // tower-to-tower centre distance

// ==== DECK ====
DECK_L  = 200;              // along the road
DECK_W  = 120;              // across the road
DECK_T  = 6;                // thickness
DECK_LIFT = 180;            // vertical travel

// ==== COUNTERWEIGHT ====
CW_L  = 60;
CW_W  = 40;
CW_H  = 60;
CW_WALL = 3;
CW_NUT_POCKET_D = 14;       // M8 nut across-flats + clearance
CW_NUT_POCKET_H = 8;

// ==== PULLEY ====
PULLEY_D       = 50;
PULLEY_BORE    = 6.2;       // 6 mm shaft + 0.2 clearance
PULLEY_W       = 20;
PULLEY_GROOVE_D = 1.4;      // 1 mm cable + 0.4 clearance
PULLEY_HUB_D   = 12;
PULLEY_HUB_H   = 8;

// ==== MOTOR ====
MOTOR_BODY_D   = 25;        // JGA25-370 body
MOTOR_BODY_L   = 32;
MOTOR_GEARBOX_L = 19;
MOTOR_SHAFT_D  = 6.2;       // 6 mm shaft + 0.2 clearance
MOTOR_FLAT_W   = 5.5;
MOTOR_MOUNT_W  = 35;
MOTOR_MOUNT_T  = 5;
MOTOR_MOUNT_HOLE_D = 3.2;   // M3 clearance

// ==== CABLE GUIDE ====
CABLE_GUIDE_W = 40;
CABLE_GUIDE_D = 30;
CABLE_GUIDE_H = 25;
CABLE_GUIDE_GROOVE_R = 0.7; // half of 1.4 cable channel

// ==== ROAD BARRIER ====
BARRIER_L = 80;
BARRIER_W = 15;
BARRIER_T = 8;
BARRIER_SERVO_HORN_D = 6;

// ==== PCB ENCLOSURE ====
PCB_X = 100;
PCB_Y = 80;
PCB_T = 1.6;
ENC_WALL = 2.5;
ENC_GAP  = 0.3;
ENC_PCB_STANDOFF_H = 5;
ENC_LID_H = 8;
ENC_BASE_H = PCB_T + ENC_PCB_STANDOFF_H + 8;
ENC_OUTER_X = PCB_X + 2*(ENC_WALL + ENC_GAP);
ENC_OUTER_Y = PCB_Y + 2*(ENC_WALL + ENC_GAP);

// ==== CAMERA MOUNT (ESP32-CAM AI-Thinker) ====
CAM_BOARD_X = 40.5;
CAM_BOARD_Y = 27;
CAM_BOARD_T = 1.6;
CAM_LENS_D  = 9.5;
CAM_GANTRY_H = 220;          // height above road for FOV
CAM_TILT_DEG = 25;

// ==== TFT DISPLAY MOUNT ====
// 2.8" ILI9341 with XPT2046 — common module 86×56×4 mm with 8 mm header on one side
TFT_BOARD_X = 86;
TFT_BOARD_Y = 56;
TFT_BOARD_T = 4;
TFT_VISIBLE_X = 58;          // active area
TFT_VISIBLE_Y = 44;
TFT_TILT_DEG = 35;           // Q5 ratified — 35° tilt
TFT_BEZEL = 5;
TFT_BACK_DEPTH = 18;         // header height behind board

// ==== HARDWARE ====
M3_CLEAR  = 3.2;
M3_TAP    = 2.8;
M3_HEAD_D = 6.0;
M3_HEAD_H = 3.0;
M3_INSERT_D = 4.2;           // brass heat-set insert OD
M3_INSERT_H = 5.0;
M8_BOLT_D = 8.4;

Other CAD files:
cad/stl/05_counterweight_right.stl
cad/scad/01_tower_left.scad
cad/scad/02_tower_right.scad
cad/scad/03_bridge_deck_section.scad
cad/scad/04_counterweight_left.scad
cad/scad/05_counterweight_right.scad
cad/scad/08_cable_guide.scad
cad/scad/09_road_barrier.scad
cad/scad/10_base_plate_section.scad
cad/scad/11_pcb_enclosure.scad
cad/scad/12_camera_mount.scad
cad/scad/13_tft_display_mount.scad
cad/scad/assembly.scad
cad/stl/06_pulley_wheel.stl
cad/stl/07_motor_mount.stl

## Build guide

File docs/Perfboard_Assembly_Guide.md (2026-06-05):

# Vertical Lift Bridge — Perfboard Assembly Guide

This guide gives the **exact pin-to-pin connection for every component** in the
current build, soldered **one module at a time**, each followed by a quick test.
Follow it top to bottom. Every wire is listed — nothing is left to interpretation.

> **Golden rules**
> 1. The ESP32 logic is **3.3 V**. Never feed a 5 V signal into any ESP32 GPIO.
> 2. Build and **measure each power rail before** connecting any chip.
> 3. Wire one module, test it, then move to the next. Do not wire everything first.
> 4. Use **header pins** for anything that leaves the board (motor, servos, lasers,
>    LDRs, screen, E-stop, panel) so parts can be unplugged.

---

## 0. What is and isn't on this board

### Components used (this build)
| Qty | Component | Logic level |
| :-- | :--- | :--- |
| 1 | ESP32-WROOM-32 38-pin DevKit | 3.3 V |
| 1 | L298N dual H-bridge motor module | 12 V power / 3.3 V logic in |
| 1 | JGA25-370 12 V DC gearmotor | 12 V |
| 1 | 5 V relay module (1-channel, with onboard driver) | 5 V coil / 3.3 V IN |
| 1 | 74HC595 shift register (DIP-16) | 3.3 V |
| 6 | LEDs: Road R/Y/G + Marine R/Y/G | 3.3 V via 220 Ω |
| 6 | 220 Ω resistors (one per LED) | — |
| 2 | SG90 micro servo (barriers) | 5 V power / 3.3 V signal |
| 4 | Laser emitter module (break-beam source) | 5 V |
| 4 | LDR receiver module with digital out (DO) | **3.3 V** |
| 1 | ILI9341 2.8" TFT + XPT2046 touch | 3.3 V |
| 1 | Mushroom E-stop, **NC** contact | 3.3 V |
| 1 | 10 kΩ resistor (E-stop pull-up) | — |
| 5 | Tactile push-buttons (operator panel) | 3.3 V |
| 5 | 1 kΩ resistors (panel ladder string) | — |
| 1 | 10 kΩ resistor (panel ladder pull-up) | — |
| 1 | 12 V / ≥3 A barrel jack | 12 V |
| 1 | LM2596 buck module (12 V → 5 V) | — |
| 1 | AMS1117-3.3 regulator (5 V → 3.3 V) | — |
| — | 100 nF caps (one per IC), 1× 470–1000 µF on 5 V | — |

### Deliberately NOT installed (do not wire these)
| Item | Reason | Pin left… |
| :--- | :--- | :--- |
| Position potentiometer | Positioning is **timer-based** in firmware | GPIO 35 unconnected |
| Limit switches | End-stops are **timer-based** in firmware | GPIO 39 unconnected |
| Piezo buzzer | Disabled to keep UART TX0 free (`PIN_BUZZER = -1`) | GPIO 1 unconnected |
| ESP32-CAM / vision | Vision module omitted from this build | GPIO 17 unconnected |

---

## 1. Power architecture

```
        12 V Barrel Jack ──┬──────────────► LM2596 IN+        (buck converter)
                           │                LM2596 OUT+ ─────► 5 V RAIL
                           │                                   │
                           │                          AMS1117-3.3 IN ─► 3.3 V RAIL
                           │
                           └──► Relay COM ──(NO)──► L298N +12 V (motor supply, gated by relay)

   GND of jack, LM2596, AMS1117, ESP32, every module ───► one COMMON GND RAIL
```

- **ESP32 is powered from the 5 V rail** (into its `VIN`/`5V` pin). Its onboard
  regulator makes the chip's own 3.3 V.
- **The 3.3 V RAIL (AMS1117) powers all 3.3 V peripherals** (TFT, 74HC595, LDR
  receivers, and every pull-up).
- **Leave the ESP32 `3V3` pin unconnected** (do not tie it to the AMS1117 rail —
  avoid two 3.3 V sources fighting).
- **Rail summary:** 12 V (motor only, via relay), 5 V (ESP32 VIN, servos, relay
  coil, laser emitters), 3.3 V (all logic + sensors + pull-ups), common GND.

### Phase A — Build & verify the rails FIRST
1. Solder the barrel jack. Mark its **+** (center) and **–** terminals.
2. Jack **+12 V → LM2596 IN+**; jack **– → COMMON GND RAIL**; **LM2596 IN– → GND**.
3. **Before connecting anything to the output**, power the jack and turn the
   LM2596 trimpot until **OUT+ reads exactly 5.0 V** vs GND. Then power off.
4. LM2596 **OUT+ → 5 V RAIL**; **OUT– → GND RAIL**.
5. **5 V RAIL → AMS1117 IN**, **AMS1117 GND → GND RAIL**, **AMS1117 OUT → 3.3 V RAIL**.
6. Add a **470–1000 µF** cap across 5 V↔GND, and a **100 nF** across 3.3 V↔GND.
7. **TEST (multimeter):** 5 V rail = 5.0 V, 3.3 V rail = 3.3 V, GND continuous
   everywhere. **Do not proceed until correct**, or you will destroy the ESP32.

---

## 2. ESP32 master pin map (single source of truth)

Solder two 19-pin female header strips and plug the ESP32 in (do not solder the
module directly). Every GPIO this firmware uses:

| GPIO | Net | Module |
| :--- | :--- | :--- |
| VIN (5V) | ← 5 V RAIL | Power in |
| GND (×) | ← GND RAIL | Power |
| 3V3 | **leave unconnected** | — |
| 25 | L298N IN1 | Motor (up) |
| 26 | L298N IN2 | Motor (down) |
| 32 | Relay IN | Motor power cutoff |
| 14 | TFT SCK / T_CLK | Display + touch clock |
| 13 | TFT MOSI / T_DIN | Display + touch data-out |
| 12 | TFT MISO / T_DO | Display + touch data-in |
| 15 | TFT CS | Display chip-select |
| 2 | TFT DC | Display data/command |
| 33 | TOUCH T_CS | Touch chip-select |
| 23 | 74HC595 SER (pin 14) | Shift-register data |
| 4 | 74HC595 SRCLK (pin 11) | Shift-register clock |
| 27 | 74HC595 RCLK (pin 12) | Shift-register latch |
| 16 | Both servo signals | Barriers (shared) |
| 18 | LDR1 DO | Laser upstream A |
| 19 | LDR2 DO | Laser upstream B |
| 21 | LDR3 DO | Laser downstream A |
| 22 | LDR4 DO | Laser downstream B |
| 36 | E-stop + 10 kΩ pull-up | Safety (input-only) |
| 34 | Panel ladder node | Operator panel (input-only) |
| 1 | **unconnected** (buzzer omitted) | — |
| 17 | **unconnected** (vision omitted) | — |
| 35 | **unconnected** (pot omitted) | — |
| 39 | **unconnected** (limits omitted) | — |

### Phase B — ESP32 power
| From | To |
| :--- | :--- |
| ESP32 `VIN` / `5V` | 5 V RAIL |
| ESP32 `GND` (all GND pins) | GND RAIL |

**TEST:** Plug in 12 V (USB may stay connected for the serial monitor). The
ESP32 power LED lights; serial @115200 prints the boot banner.

---

## 3. Module-by-module wiring

Wire each table fully, then run its test before moving on.

### Module 1 — Safety relay (motor power cutoff)
The relay sits between the 12 V jack and the L298N so firmware (GPIO 32) and the
hardware E-stop can cut motor power.

| From | To | Purpose |
| :--- | :--- | :--- |
| Relay `VCC` | 5 V RAIL | Coil/driver power |
| Relay `GND` | GND RAIL | Common ground |
| Relay `IN` | ESP32 GPIO 32 | Firmware control |
| Relay `COM` | Barrel jack +12 V | Switched-in supply |
| Relay `NO` | L298N `+12V` (VS) | Switched-out to motor |

**TEST:** On boot the firmware energises the relay once no fault/E-stop — you
hear it click and `NO` reads ~12 V. Press E-stop → it clicks off, `NO` → 0 V.

### Module 2 — L298N motor driver + gearmotor
Keep the **ENA and ENB jumper caps installed** (ties enables high on-board) and
the **onboard 5 V-regulator jumper installed**. Speed/direction ride on IN1/IN2.

| From | To | Purpose |
| :--- | :--- | :--- |
| L298N `+12V` (VS) | Relay `NO` (see Module 1) | Motor supply (gated) |
| L298N `GND` | GND RAIL | Common ground |
| L298N `IN1` | ESP32 GPIO 25 | Up PWM |
| L298N `IN2` | ESP32 GPIO 26 | Down PWM |
| L298N `OUT1` | Gearmotor terminal A | Motor + |
| L298N `OUT2` | Gearmotor terminal B | Motor – |
| L298N `ENA` jumper | installed (on-board) | Channel A enabled |

> Do **not** connect the L298N `+5V` terminal to your 5 V rail — the module
> makes its own logic 5 V. Only `+12V`, `GND`, `IN1`, `IN2`, `OUT1`, `OUT2` are used.

**TEST:** From the HMI press RAISE; the motor runs one way, then LOWER reverses
it. If it runs the wrong way, swap `OUT1`/`OUT2`.

### Module 3 — Servo barriers (2 × SG90, mirrored on one signal)
Both servos share GPIO 16 (they move together). SG90 wires: **orange = signal,
red = +5 V, brown = GND.**

| From | To | Purpose |
| :--- | :--- | :--- |
| Servo 1 orange | ESP32 GPIO 16 | Shared PWM signal |
| Servo 2 orange | ESP32 GPIO 16 | Shared PWM signal |
| Servo 1 & 2 red | 5 V RAIL | Servo power |
| Servo 1 & 2 brown | GND RAIL | Common ground |

> Add a **470 µF** cap across 5 V↔GND near the servos to absorb their current spikes.

**TEST:** On boot the barriers sweep to the up position. RAISE closes them (down),
returning to idle opens them (up).

### Module 4 — 74HC595 shift register + traffic lights
DIP-16 pinout (notch up, pin 1 top-left):

```
   Q1 1 ┌──┐16 VCC
   Q2 2 │  │15 Q0
   Q3 3 │  │14 SER  (DATA)
   Q4 4 │  │13 OE   (active-low)
   Q5 5 │  │12 RCLK (LATCH)
   Q6 6 │  │11 SRCLK(CLOCK)
   Q7 7 │  │10 SRCLR(active-low)
  GND 8 └──┘ 9 Q7'
```

| From | To | Purpose |
| :--- | :--- | :--- |
| 595 pin 16 `VCC` | 3.3 V RAIL | Logic power |
| 595 pin 8 `GND` | GND RAIL | Common ground |
| 595 pin 10 `SRCLR` | 3.3 V RAIL | Disable reset (active-low) |
| 595 pin 13 `OE` | GND RAIL | Enable outputs (active-low) |
| 595 pin 14 `SER` | ESP32 GPIO 23 | Data |
| 595 pin 11 `SRCLK` | ESP32 GPIO 4 | Clock |
| 595 pin 12 `RCLK` | ESP32 GPIO 27 | Latch |
| 595 pin 16↔8 | 100 nF cap across | Decoupling |

Traffic LEDs — **anode → 595 output**, **cathode → 220 Ω → GND RAIL** (one
resistor per LED):

| 595 output | Pin | LED |
| :--- | :--- | :--- |
| Q0 | 15 | **Road RED** |
| Q1 | 1 | **Road YELLOW** |
| Q2 | 2 | **Road GREEN** |
| Q3 | 3 | **Marine RED** |
| Q4 | 4 | **Marine YELLOW** |
| Q5 | 5 | **Marine GREEN** |

(Q6 pin 6, Q7 pin 7, Q7' pin 9 — leave unconnected.)

**TEST:** Idle = Road GREEN + Marine RED. RAISE → Road RED. Fully up (HOLD) →
Marine GREEN. Each LED should be steady (no flicker).

### Module 5 — Laser break-beam (4 channels)
Each channel = one **laser emitter** aimed across the gap at one **LDR receiver**
module. Emitters take 5 V (they never touch a GPIO). **Receivers must be powered
from 3.3 V** so their digital output (`DO`) is GPIO-safe.

| From | To | Purpose |
| :--- | :--- | :--- |
| All 4 laser emitter `VCC` | 5 V RAIL | Emitter power |
| All 4 laser emitter `GND` | GND RAIL | Common ground |
| All 4 LDR receiver `VCC` | **3.3 V RAIL** | Receiver power (GPIO-safe DO) |
| All 4 LDR receiver `GND` | GND RAIL | Common ground |
| LDR1 `DO` (Upstream A) | ESP32 GPIO 18 | Direction sensing |
| LDR2 `DO` (Upstream B) | ESP32 GPIO 19 | Direction sensing |
| LDR3 `DO` (Downstream A) | ESP32 GPIO 21 | Direction sensing |
| LDR4 `DO` (Downstream B) | ESP32 GPIO 22 | Direction sensing |

> Aim each laser at its LDR and adjust the LDR module trimpot until `DO` goes
> HIGH when the beam is clear and LOW when blocked. Beam clear = not blocked.

**TEST:** Wave a hand through Upstream A then B → HMI shows a vessel approaching.

### Module 6 — E-stop (NC mushroom button)
GPIO 36 is **input-only and has NO internal pull-up**, so an **external 10 kΩ
pull-up to 3.3 V is mandatory.** With the NC contact: closed (idle) pulls the pin
LOW; pressing opens it and the pull-up drives it HIGH = "pressed".

| From | To | Purpose |
| :--- | :--- | :--- |
| E-stop terminal 1 | ESP32 GPIO 36 | Sense |
| E-stop terminal 2 | GND RAIL | Pulls LOW when closed |
| 10 kΩ resistor | GPIO 36 → 3.3 V RAIL | **Mandatory** pull-up |

**TEST:** Idle = system runs. Press E-stop → state goes ESTOP, relay clicks off,
motor dead. Release → returns to IDLE.

### Module 7 — Operator panel (5-button resistor ladder on GPIO 34)
GPIO 34 is input-only with its own external pull-up. Build a **string of five
1 kΩ resistors** from GND, and connect each button from the **ADC node (N)** to a
different tap. Tap resistance-to-ground sets each button's ADC band.

```
   3.3 V ──[10 kΩ pull-up]──┬── N ── ESP32 GPIO 34
                            │
   N ─[BTN RAISE]──────────► T5 (5 kΩ to GND)
   N ─[BTN LOWER]──────────► T4 (4 kΩ to GND)
   N ─[BTN HOLD]───────────► T3 (3 kΩ to GND)
   N ─[BTN CLEAR_FAULT]────► T2 (2 kΩ to GND)
   N ─[BTN NEXT_SCREEN]────► T1 (1 kΩ to GND)

   String:  GND ─[1k]─ T1 ─[1k]─ T2 ─[1k]─ T3 ─[1k]─ T4 ─[1k]─ T5
```

| From | To | Purpose |
| :--- | :--- | :--- |
| 10 kΩ resistor | GPIO 34 (node N) → 3.3 V RAIL | Pull-up / reference |
| Node N | ESP32 GPIO 34 | ADC input |
| Resistor R5 (1 kΩ) | GND → T1 | Ladder bottom |
| Resistor R4 (1 kΩ) | T1 → T2 | Ladder |
| Resistor R3 (1 kΩ) | T2 → T3 | Ladder |
| Resistor R2 (1 kΩ) | T3 → T4 | Ladder |
| Resistor R1 (1 kΩ) | T4 → T5 | Ladder top |
| Button RAISE | Node N → T5 | ADC ≈ 1365 |
| Button LOWER | Node N → T4 | ADC ≈ 1167 |
| Button HOLD | Node N → T3 | ADC ≈ 943 |
| Button CLEAR_FAULT | Node N → T2 | ADC ≈ 683 |
| Button NEXT_SCREEN | Node N → T1 | ADC ≈ 372 |

**TEST:** Each press triggers exactly its action (RAISE/LOWER/HOLD/clear-fault/
next-tab). If a button triggers the wrong action, you swapped two taps.

### Module 8 — TFT display + touch (ILI9341 + XPT2046, shared SPI)
14-pin combo board. TFT and touch **share** SCK/MOSI/MISO; only the chip-selects
differ. `T_IRQ` is unused (firmware polls).

| Module pin | To | Purpose |
| :--- | :--- | :--- |
| `VCC` | 3.3 V RAIL | Power |
| `GND` | GND RAIL | Ground |
| `CS` | ESP32 GPIO 15 | Display CS |
| `RESET` | ESP32 `EN` | Reset (tied to EN) |
| `DC` / `RS` | ESP32 GPIO 2 | Data/command |
| `SDI` / `MOSI` | ESP32 GPIO 13 | SPI data out |
| `SCK` | ESP32 GPIO 14 | SPI clock |
| `LED` / `BL` | 3.3 V RAIL | Backlight (always on) |
| `SDO` / `MISO` | ESP32 GPIO 12 | SPI data in |
| `T_CLK` | ESP32 GPIO 14 | Touch clock (shared SCK) |
| `T_CS` | ESP32 GPIO 33 | Touch CS |
| `T_DIN` | ESP32 GPIO 13 | Touch data (shared MOSI) |
| `T_DO` | ESP32 GPIO 12 | Touch data (shared MISO) |
| `T_IRQ` | leave unconnected | Polled, not used |

**TEST:** UI appears with HOME/OPS/CW/SET tabs. Touch RAISE on the OPS tab and
the bridge sequence starts.

---

## 4. Final checklist & power-up

1. **Visual:** no solder bridges; every IC VCC/GND correct; LDR receivers on
   **3.3 V** (never 5 V); E-stop 10 kΩ pull-up present; ESP32 `3V3` pin unconnected.
2. **Continuity (power off):** GND continuous; no short between 12 V, 5 V, 3.3 V,
   or any of them to GND.
3. **Rails (12 V in, ESP32 out):** confirm 5.0 V and 3.3 V again under load.
4. **Boot:** serial @115200 prints the banner and each `[module] init OK` line.
5. **Dry run (deck parked at bottom):** RAISE → barriers close, counterweight
   tanks fill on the CW tab as the deck bar rises, Marine turns GREEN at the top;
   LOWER drains them back to empty. E-stop kills everything instantly.

> **Calibration:** measure the real full-travel times and set `DECK_RAISE_TIME_MS`
> / `DECK_LOWER_TIME_MS` in `firmware/src/system_types.h` so the HMI deck height
> reads true. Always power off with the **deck parked at the bottom** (no limit
> switch homes it).

---

## 5. Soldering best practices
1. **Never cross bare wires.** Use insulated jumpers where paths cross.
2. **Header pins for everything external** (motor, servos, lasers, LDRs, screen,
   E-stop, panel) so a failed part swaps out without desoldering.
3. **3.3 V vs 5 V discipline.** Any sensor output going to a GPIO must be a 3.3 V
   signal. The LDR receivers and 74HC595 are powered from 3.3 V for this reason.
4. **One 100 nF cap per IC**, right at its VCC/GND pins, plus the bulk 5 V cap.
5. **Test after every module** — never wire the whole board then power it blind.

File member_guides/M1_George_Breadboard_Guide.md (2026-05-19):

> **IMPORTANT UPDATE:** The breadboard phase of this project is strictly complete. Please transition immediately to the physical assembly phase. This includes mounting the ESP32 and components into the physical 3D printed enclosure and soldering the final PCB.

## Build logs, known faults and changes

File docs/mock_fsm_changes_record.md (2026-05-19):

# Mock FSM Changes Record

**UPDATE FOR PHYSICAL ASSEMBLY:**
As of the latest commit for the physical assembly phase, all "DEV MOCK" software bypasses have been **reverted**. This includes:
- E-stop mock
- Stall detector disable
- Serial manual injector

The breadboard phase is strictly complete, and the system now relies on actual hardware inputs for all FSM state transitions and safety mechanisms.

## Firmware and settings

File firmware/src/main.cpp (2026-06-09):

// ============================================================================
// main.cpp — Vertical Lift Bridge Control System (Group 7)
// Entry point. Initialises peripherals, creates FreeRTOS tasks, mutex, queues.
// Owner: George (M1)
// ============================================================================
#include <Arduino.h>
#include <freertos/FreeRTOS.h>
#include <freertos/task.h>
#include <freertos/queue.h>
#include <freertos/semphr.h>
#include <esp_task_wdt.h>

#include "pin_config.h"
#include "system_types.h"

// Module headers
#include "fsm/fsm_engine.h"
#include "motor/motor_driver.h"
#include "sensors/laser.h"
#include "traffic/traffic_lights.h"
#include "traffic/buzzer.h"
#include "hmi/display.h"
#include "hmi/input.h"
// task_safety drives traffic_lights_tick / buzzer_tick / input_tick
// (see below) — these headers are pulled in for those calls.
#include "counterweight/counterweight.h"
#include "safety/watchdog.h"
#include "safety/fault_register.h"
#include "safety/interlocks.h"

// ---------------------------------------------------------------------------
// Globals (declared extern in system_types.h)
// ---------------------------------------------------------------------------
SharedStatus_t      g_status            = {};
SemaphoreHandle_t   g_status_mutex      = nullptr;
QueueHandle_t       g_event_queue       = nullptr;
QueueHandle_t       g_motor_cmd_queue   = nullptr;
QueueHandle_t       g_hmi_cmd_queue     = nullptr;

// ---------------------------------------------------------------------------
// Task handles — kept for stack inspection / debug.
// ---------------------------------------------------------------------------
static TaskHandle_t h_fsm           = nullptr;
static TaskHandle_t h_motor         = nullptr;
static TaskHandle_t h_sensors       = nullptr;
static TaskHandle_t h_safety        = nullptr;
static TaskHandle_t h_hmi           = nullptr;
static TaskHandle_t h_telemetry     = nullptr;
static TaskHandle_t h_counterweight = nullptr;

// ---------------------------------------------------------------------------
// Task stack sizes (bytes) — tuned, then bumped 25% for headroom.
// ---------------------------------------------------------------------------
static constexpr uint32_t STK_FSM       = 4096;
static constexpr uint32_t STK_MOTOR     = 3072;
static constexpr uint32_t STK_SENSORS   = 3072;
static constexpr uint32_t STK_SAFETY    = 3072;
static constexpr uint32_t STK_HMI       = 8192;     // LVGL needs space
static constexpr uint32_t STK_TELEM     = 2048;
static constexpr uint32_t STK_CW       = 2048;

// ---------------------------------------------------------------------------
// Task priorities — higher = more urgent. Keep safety highest.
// ---------------------------------------------------------------------------
static constexpr UBaseType_t PRI_SAFETY     = 5;
static constexpr UBaseType_t PRI_FSM        = 4;
static constexpr UBaseType_t PRI_MOTOR      = 4;
static constexpr UBaseType_t PRI_SENSORS    = 3;
static constexpr UBaseType_t PRI_HMI        = 2;
static constexpr UBaseType_t PRI_CW         = 2;
static constexpr UBaseType_t PRI_TELEM      = 1;

// ---------------------------------------------------------------------------
// Core affinity — Core 0 reserved for safety + comms; Core 1 for HMI.
// ---------------------------------------------------------------------------
static constexpr BaseType_t CORE_0 = 0;
static constexpr BaseType_t CORE_1 = 1;

// ---------------------------------------------------------------------------
// Forward declarations of task functions.
// ---------------------------------------------------------------------------
static void task_fsm        (void* arg);
static void task_motor      (void* arg);
static void task_sensors    (void* arg);
static void task_safety         (void* arg);
static void task_counterweight  (void* arg);
static void task_telemetry      (void* arg);

// HMI task is implemented in hmi/display.cpp because it owns LVGL tick + flush.
extern void task_hmi(void* arg);

// ===========================================================================
// setup()
// ===========================================================================
void setup() {
    Serial.begin(115200);
    delay(200);
    Serial.println("\n\n=== VLB Group 7 — Boot ===");
    Serial.printf("ESP32 SDK: %s | Sketch: %s\n",
                  ESP.getSdkVersion(), __DATE__);

    // -- Sync & queues -----------------------------------------------------
    g_status_mutex      = xSemaphoreCreateMutex();
    g_event_queue       = xQueueCreate(32, sizeof(SystemEvent_t));
    g_motor_cmd_queue   = xQueueCreate(8,  sizeof(MotorCommand_t));
    g_hmi_cmd_queue     = xQueueCreate(16, sizeof(uint8_t));
    configASSERT(g_status_mutex);
    configASSERT(g_event_queue);
    configASSERT(g_motor_cmd_queue);
    configASSERT(g_hmi_cmd_queue);

    // Init shared state
    g_status.state = STATE_INIT;
    g_status.uptime_ms = 0;

    // -- Watchdog ---------------------------------------------------------
    safety_watchdog_init();        // Configures hardware TWDT
    fault_register_init();
    interlocks_init();

    // -- Peripherals (all called from Core 0) ----------------------------
    motor_driver_init();
    sensors_laser_init();
    traffic_lights_init();
    buzzer_init();
    counterweight_init();
    input_init();

    // HMI is started inside task_hmi (must run on Core 1 for LVGL).
    Serial.println("[boot] Peripherals OK");

    // -- Task creation ----------------------------------------------------
    xTaskCreatePinnedToCore(task_safety,    "safety",   STK_SAFETY,
                            nullptr, PRI_SAFETY, &h_safety,    CORE_0);
    xTaskCreatePinnedToCore(task_fsm,       "fsm",      STK_FSM,
                            nullptr, PRI_FSM,    &h_fsm,       CORE_0);
    xTaskCreatePinnedToCore(task_motor,     "motor",    STK_MOTOR,
                            nullptr, PRI_MOTOR,  &h_motor,     CORE_0);
    xTaskCreatePinnedToCore(task_sensors,   "sensors",  STK_SENSORS,
                            nullptr, PRI_SENSORS, &h_sensors,  CORE_0);
    xTaskCreatePinnedToCore(task_counterweight, "cw",    STK_CW,
                            nullptr, PRI_CW,     &h_counterweight, CORE_0);
    xTaskCreatePinnedToCore(task_telemetry, "telem",    STK_TELEM,
                            nullptr, PRI_TELEM,  &h_telemetry, CORE_0);

    // HMI task — pinned to Core 1 (Arduino's loop core).
    xTaskCreatePinnedToCore(task_hmi,       "hmi",      STK_HMI,
                            nullptr, PRI_HMI,    &h_hmi,       CORE_1);

    Serial.println("[boot] Tasks created — entering scheduler");

    // Transition to IDLE once tasks are spinning.
    SystemEvent_t e = EVT_NONE;
    xQueueSend(g_event_queue, &e, 0);
}

// ===========================================================================
// loop() — Arduino runs this on Core 1; we keep it idle.
// ===========================================================================
void loop() {
    vTaskDelay(pdMS_TO_TICKS(1000));
    safety_watchdog_kick_main();
}

// ===========================================================================
// task_fsm — pulls events from queue, runs FSM, dispatches motor/light cmds.
// ===========================================================================
static void task_fsm(void* arg) {
    fsm_engine_init();
    SystemEvent_t evt;
    TickType_t last_tick = xTaskGetTickCount();
    for (;;) {
        // Wait up to 100 ms for an event
        if (xQueueReceive(g_event_queue, &evt, pdMS_TO_TICKS(100)) == pdTRUE) {
            fsm_engine_handle(evt);
        } else {
            fsm_engine_handle(EVT_TICK_100MS);
        }
        safety_watchdog_kick_fsm();
        vTaskDelayUntil(&last_tick, pdMS_TO_TICKS(20));
    }
}

// ===========================================================================
// task_motor — L298N H-bridge drive + timer-based deck-position estimate.
// No potentiometer and no limit switches: position is integrated from motor
// run-time and pinned to the end-stops each traverse (see motor_driver.cpp).
// No current monitoring — the L298N module has no MCU-facing current sense.
// ===========================================================================
static void task_motor(void* arg) {
    MotorCommand_t cmd;
    for (;;) {
        if (xQueueReceive(g_motor_cmd_queue, &cmd, pdMS_TO_TICKS(20)) == pdTRUE) {
            motor_driver_apply(cmd);
        }
        motor_driver_tick();   // integrate position, emit virtual end-stops, runaway guard
        safety_watchdog_kick_motor();
    }
}

// ===========================================================================
// task_sensors — Laser break-beam ranging at 20 Hz.
// ===========================================================================
static void task_sensors(void* arg) {
    TickType_t last = xTaskGetTickCount();
    for (;;) {
        sensors_laser_tick();
        safety_watchdog_kick_sensors();
        vTaskDelayUntil(&last, pdMS_TO_TICKS(50));   // 20 Hz
    }
}

// ===========================================================================
// task_safety — evaluates fault flags, drives E-stop relay, latches faults.
// ===========================================================================
static void task_safety(void* arg) {
    // Cover task_safety itself with the hardware TWDT — the software watchdog
    // checker runs in this task, so it cannot detect a hang here. A stall now
    // trips the 5 s TWDT (panic + reset) instead of going unnoticed.
    safety_watchdog_subscribe_task();

    TickType_t last = xTaskGetTickCount();
    uint8_t   slow_div = 0;
    for (;;) {
        interlocks_evaluate();
        fault_register_evaluate();
        safety_watchdog_check_all();

        // Operator panel scan: 20 Hz is plenty for a 5-button resistor ladder.
        input_tick();

        // Traffic lights + buzzer: drive at 10 Hz (every 2nd safety tick).
        // Lower than safety so blink phase is human-pleasant; higher than
        // task_telemetry so state changes are visible within ~100 ms.
        if (++slow_div >= 2) {
            slow_div = 0;
            traffic_lights_tick();
            buzzer_tick();
        }

        safety_watchdog_feed_hw();                   // feed the hardware TWDT
        vTaskDelayUntil(&last, pdMS_TO_TICKS(50));   // 20 Hz
    }
}

// ===========================================================================
// task_counterweight — simulated dynamic counterweight system at 20 Hz.
// ===========================================================================
static void task_counterweight(void* arg) {
    TickType_t last = xTaskGetTickCount();
    for (;;) {
        counterweight_tick();
        vTaskDelayUntil(&last, pdMS_TO_TICKS(50));   // 20 Hz
    }
}

// ===========================================================================
// task_telemetry — uptime heartbeat. 1 Hz.
// (CPU-load reporting and voltage-rail monitoring are intentionally omitted.)
// ===========================================================================
static void task_telemetry(void* arg) {
    TickType_t last = xTaskGetTickCount();
    for (;;) {
        if (xSemaphoreTake(g_status_mutex, pdMS_TO_TICKS(100)) == pdTRUE) {
            g_status.uptime_ms = millis();
            xSemaphoreGive(g_status_mutex);
        }
        vTaskDelayUntil(&last, pdMS_TO_TICKS(1000));
    }
}

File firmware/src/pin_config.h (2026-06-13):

// pin_config.h  ::  vertical-lift-bridge :: GPIO assignments
// SINGLE SOURCE OF TRUTH. 
// v3.0 — May 2026. Major refactor to resolve all L4/L8 pin conflicts.
// Shared LDR input enables quad-laser setup without sacrificing pins.
// Input-only pins perfectly utilized for safety and ADCs.

#pragma once

// ====================== MOTOR (L298N dual H-bridge) =================
// ENA tied high on the module; PWM rides directly on IN1/IN2.
#define PIN_MOTOR_IN1        25     // LEDC ch 0  (L298N IN1, up)
#define PIN_MOTOR_IN2        26     // LEDC ch 1  (L298N IN2, down)
#define PIN_MOTOR_RELAY      32     // Safety relay (cuts L298N supply)
#define PIN_DECK_POSITION    35     // UNUSED — position pot omitted (timer-based positioning). Reserved spare; do not reassign.

#define LEDC_MOTOR_FREQ_HZ   4000
#define LEDC_MOTOR_RES_BITS  13
#define LEDC_MOTOR_CH_FWD    0
#define LEDC_MOTOR_CH_REV    1

// ====================== TFT DISPLAY & TOUCH =========================
#define PIN_TFT_SCK          14
#define PIN_TFT_MOSI         13
#define PIN_TFT_MISO         12
#define PIN_TFT_CS           15
#define PIN_TFT_DC            2
#define PIN_TFT_RST          -1     // Hardware tie to EN
#define PIN_TFT_BL           -1     // Hardware tie to 3.3V
#define PIN_TOUCH_CS         33
#define PIN_TOUCH_IRQ        -1     // SPI Polling

// ====================== LASER BREAK-BEAM (LDR ×4) ====================
#define PIN_LDR1_IN          18     // Upstream A
#define PIN_LDR2_IN          19     // Upstream B
#define PIN_LDR3_IN          21     // Downstream A
#define PIN_LDR4_IN          22     // Downstream B

// ====================== LIMIT SWITCHES (omitted) ====================
// Limit switches are omitted in this build — end-stops are timer-estimated.
//#define PIN_LIMIT_ANYHIT     39     // UNUSED (input-only). Reserved spare; do not reassign.

// ====================== SPARE PINS ==================================
// Vision module (ESP32-CAM) and its UART2 link are omitted from this build.
// GPIO16 carries the barrier servos (see SERVOS). GPIO17 is the only true spare.
#define PIN_SPARE_GPIO17     17     // unused / spare

// ====================== TRAFFIC LIGHTS (74HC595) ====================
#define PIN_595_DATA         23
#define PIN_595_CLOCK         4
#define PIN_595_LATCH        27
#define PIN_595_OE_N         -1     // Hardware tie to GND

// ====================== SERVOS (SG90 ×2) ============================
#define PIN_SERVO_LEFT       16     // Moved off GPIO3 (UART0 RX) to free serial monitor
#define PIN_SERVO_RIGHT      16     // Both servos driven by same PWM pin
#define LEDC_SERVO_FREQ_HZ   50
#define LEDC_SERVO_RES_BITS  16
#define LEDC_SERVO_LEFT_CH    3
#define LEDC_SERVO_RIGHT_CH   3

// ====================== BUZZER ======================================
#define PIN_BUZZER           -1     // Disabled to preserve UART TX0
#define LEDC_BUZZER_CH        5

// ====================== OPERATOR PANEL & ESTOP ======================
#define PIN_BTN_LADDER       34     // ADC1_CH6
#define PIN_ESTOP_IRQ        36     // Input-only

// ====================== ALIASES =====================================
#define PIN_MOT_IN1          PIN_MOTOR_IN1
#define PIN_MOT_IN2          PIN_MOTOR_IN2
#define PIN_ESTOP            PIN_ESTOP_IRQ
#define PIN_RELAY            PIN_MOTOR_RELAY
#define PIN_SERVO_L          PIN_SERVO_LEFT
#define PIN_SERVO_R          PIN_SERVO_RIGHT
#define PIN_595_OE           PIN_595_OE_N

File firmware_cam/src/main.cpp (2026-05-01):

// ============================================================================
// firmware_cam/src/main.cpp — ESP32-CAM companion.
// Owner: M3 Cindy
//
// Captures grayscale QQVGA (160x120) frames at ~10 Hz, runs a frame-difference
// algorithm to detect motion in a configurable ROI, and emits one JSON line
// per frame to UART0 (serial pins of the AI-Thinker module's bottom header).
//
// JSON format:
//   {"t":<millis>,"v":<0|1>,"c":<0..100>,"x":<bbox.x>,"y":<bbox.y>,
//    "w":<bbox.w>,"h":<bbox.h>}
//
// Hardware: AI-Thinker ESP32-CAM, OV2640 camera, 5V supply.
// Wiring to ESP32 main board:
//   CAM TX0  -> ESP32 GPIO16 (UART2 RX)
//   CAM RX0  -> ESP32 GPIO17 (UART2 TX)   [optional, not used in v1]
//   CAM GND  -> ESP32 GND (common)
//   CAM 5V   -> 12V→5V buck output (separate from ESP32 5V to avoid brownout)
// ============================================================================
#include "esp_camera.h"
#include <Arduino.h>

// AI-Thinker pinout
#define PWDN_GPIO_NUM     32
#define RESET_GPIO_NUM    -1
#define XCLK_GPIO_NUM      0
#define SIOD_GPIO_NUM     26
#define SIOC_GPIO_NUM     27
#define Y9_GPIO_NUM       35
#define Y8_GPIO_NUM       34
#define Y7_GPIO_NUM       39
#define Y6_GPIO_NUM       36
#define Y5_GPIO_NUM       21
#define Y4_GPIO_NUM       19
#define Y3_GPIO_NUM       18
#define Y2_GPIO_NUM        5
#define VSYNC_GPIO_NUM    25
#define HREF_GPIO_NUM     23
#define PCLK_GPIO_NUM     22

#define ROI_X    20
#define ROI_Y    30
#define ROI_W   120
#define ROI_H    60
#define MOTION_THRESHOLD   24      // Per-pixel intensity delta
#define DETECT_PCT_THRESH  6       // % pixels above threshold => "vehicle"
#define DETECT_HOLD_MS     400     // Latch detection for this long

static uint8_t  s_prev[ROI_W * ROI_H];
static bool     s_have_prev = false;
static uint32_t s_last_detect_ms = 0;

void setup() {
    Serial.begin(115200);
    delay(200);

    camera_config_t config = {};
    config.ledc_channel = LEDC_CHANNEL_0;
    config.ledc_timer   = LEDC_TIMER_0;
    config.pin_d0 = Y2_GPIO_NUM; config.pin_d1 = Y3_GPIO_NUM;
    config.pin_d2 = Y4_GPIO_NUM; config.pin_d3 = Y5_GPIO_NUM;
    config.pin_d4 = Y6_GPIO_NUM; config.pin_d5 = Y7_GPIO_NUM;
    config.pin_d6 = Y8_GPIO_NUM; config.pin_d7 = Y9_GPIO_NUM;
    config.pin_xclk = XCLK_GPIO_NUM; config.pin_pclk = PCLK_GPIO_NUM;
    config.pin_vsync = VSYNC_GPIO_NUM; config.pin_href = HREF_GPIO_NUM;
    config.pin_sccb_sda = SIOD_GPIO_NUM; config.pin_sccb_scl = SIOC_GPIO_NUM;
    config.pin_pwdn = PWDN_GPIO_NUM; config.pin_reset = RESET_GPIO_NUM;
    config.xclk_freq_hz = 20000000;
    config.frame_size   = FRAMESIZE_QQVGA;     // 160x120
    config.pixel_format = PIXFORMAT_GRAYSCALE; // 1 byte / pixel
    config.fb_count     = 2;
    config.fb_location  = CAMERA_FB_IN_PSRAM;
    config.grab_mode    = CAMERA_GRAB_LATEST;
    config.jpeg_quality = 12;

    esp_err_t err = esp_camera_init(&config);
    if (err != ESP_OK) {
        Serial.printf("{\"err\":\"cam_init_%d\"}\n", err);
        while (true) delay(1000);
    }
    Serial.println("{\"boot\":\"ok\"}");
}

void loop() {
    camera_fb_t* fb = esp_camera_fb_get();
    if (!fb) {
        delay(100);
        return;
    }

    // ROI extraction
    static uint8_t roi[ROI_W * ROI_H];
    for (int y = 0; y < ROI_H; y++) {
        const uint8_t* src = fb->buf + (ROI_Y + y) * fb->width + ROI_X;
        memcpy(roi + y * ROI_W, src, ROI_W);
    }
    esp_camera_fb_return(fb);

    bool vehicle = false;
    int  motion_pct = 0;
    int  bbox_x1 = ROI_W, bbox_y1 = ROI_H, bbox_x2 = 0, bbox_y2 = 0;

    if (s_have_prev) {
        int hits = 0;
        for (int y = 0; y < ROI_H; y++) {
            for (int x = 0; x < ROI_W; x++) {
                int idx = y * ROI_W + x;
                int d = (int)roi[idx] - (int)s_prev[idx];
                if (d < 0) d = -d;
                if (d > MOTION_THRESHOLD) {
                    hits++;
                    if (x < bbox_x1) bbox_x1 = x;
                    if (y < bbox_y1) bbox_y1 = y;
                    if (x > bbox_x2) bbox_x2 = x;
                    if (y > bbox_y2) bbox_y2 = y;
                }
            }
        }
        motion_pct = (hits * 100) / (ROI_W * ROI_H);
        if (motion_pct > DETECT_PCT_THRESH) {
            vehicle = true;
            s_last_detect_ms = millis();
        } else if (millis() - s_last_detect_ms < DETECT_HOLD_MS) {
            vehicle = true;     // Hold detection briefly
        }
    }
    memcpy(s_prev, roi, ROI_W * ROI_H);
    s_have_prev = true;

    int bbox_w = (bbox_x2 > bbox_x1) ? (bbox_x2 - bbox_x1) : 0;
    int bbox_h = (bbox_y2 > bbox_y1) ? (bbox_y2 - bbox_y1) : 0;

    Serial.printf("{\"t\":%lu,\"v\":%d,\"c\":%d,\"x\":%d,\"y\":%d,\"w\":%d,\"h\":%d}\n",
                  millis(), vehicle ? 1 : 0, motion_pct,
                  bbox_x1 + ROI_X, bbox_y1 + ROI_Y, bbox_w, bbox_h);

    delay(80);   // ~10 Hz cap (camera capture itself is the floor)
}

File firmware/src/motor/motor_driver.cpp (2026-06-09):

// ============================================================================
// motor/motor_driver.cpp — L298N dual H-bridge control
// + TIMER-BASED deck-position estimate (no potentiometer, no limit switches).
// Owner: M2 Eugene (Mechanism)
//
// Pin mapping (see pin_config.h):
//   MOT_IN1 (forward/up)    — GPIO25  (LEDC ch0, 13-bit, 4 kHz)
//   MOT_IN2 (reverse/down)  — GPIO26  (LEDC ch1, 13-bit, 4 kHz)
//   ENA                     — tied HIGH on the L298N module
//                             (PWM rides on IN1/IN2 directly)
//
// Positioning model
// -----------------
// The position potentiometer and the limit switches are OMITTED in this
// build. Deck height is integrated from motor run-time: the firmware knows
// the deck travels the full DECK_HEIGHT_MAX_MM in DECK_RAISE_TIME_MS going up
// and DECK_LOWER_TIME_MS coming down (gravity-assisted, so faster). Each tick
// adds/subtracts the distance covered since the previous tick.
//
// Drift control: the estimate is pinned HARD to the mechanical end-stops
// (0 mm / DECK_HEIGHT_MAX_MM) the moment a traverse completes, and a virtual
// EVT_TOP_LIMIT_HIT / EVT_BOTTOM_LIMIT_HIT is emitted there. Because every
// full raise ends pinned at MAX and every full lower ends pinned at 0, the
// estimate re-synchronises twice per cycle and error cannot accumulate.
// ASSUMPTION: the deck is parked at the bottom (0 mm) at power-on.
//
// Runaway guard: with no feedback we cannot detect a true mechanical stall,
// but we DO bound how long the motor may be commanded to move. If a move runs
// longer than a full traverse + MOTION_TIMEOUT_MARGIN_MS without reaching its
// end-stop, FAULT_STALL is raised and the FSM trips to FAULT (relay cut).
//
// Current sensing: the L298N module exposes no MCU-facing current-sense
// output, so motor_current_ma stays 0 and FAULT_OVERCURRENT is never raised —
// the L298N's on-chip thermal shutdown is the hardware safety net.
// ============================================================================
#include "motor_driver.h"
#include "../pin_config.h"
#include <Arduino.h>
#include <freertos/FreeRTOS.h>
#include <freertos/semphr.h>

// ---------------------------------------------------------------------------
// LEDC channel configuration
// ---------------------------------------------------------------------------
#define LEDC_CH_IN1     0          // motor IN1 (forward/up) PWM
#define LEDC_CH_IN2     1          // motor IN2 (reverse/down) PWM
#define LEDC_RES_BITS   LEDC_MOTOR_RES_BITS // 0..8191 duty (matches MOTOR_PWM_MAX)
#define LEDC_FREQ_HZ    LEDC_MOTOR_FREQ_HZ  // 4000 Hz, satisfying 80MHz APB limit

// ---------------------------------------------------------------------------
// State
// ---------------------------------------------------------------------------
static MotorDirection_t s_dir          = MOTOR_STOP;
static uint16_t         s_duty         = 0;

// Timer-based position estimate (millimetres, kept in float for sub-mm steps).
static float            s_pos_mm       = 0.0f;   // assume parked at bottom on boot
static uint32_t         s_last_tick_ms = 0;      // for dt integration
static uint32_t         s_move_start_ms= 0;      // when the current UP/DOWN move began
static bool             s_moving       = false;  // true while dir is UP or DOWN

// ---------------------------------------------------------------------------
// Public API
// ---------------------------------------------------------------------------
void motor_driver_init(void) {
    // PWM channels (ENA tied high on the L298N module; speed/direction via
    // PWM on IN1/IN2).
    ledcSetup(LEDC_CH_IN1, LEDC_FREQ_HZ, LEDC_RES_BITS);
    ledcSetup(LEDC_CH_IN2, LEDC_FREQ_HZ, LEDC_RES_BITS);
    ledcAttachPin(PIN_MOT_IN1, LEDC_CH_IN1);
    ledcAttachPin(PIN_MOT_IN2, LEDC_CH_IN2);
    ledcWrite(LEDC_CH_IN1, 0);
    ledcWrite(LEDC_CH_IN2, 0);

    // Deck assumed parked at the mechanical bottom at power-on (see header).
    s_pos_mm        = 0.0f;
    s_last_tick_ms  = millis();
    s_move_start_ms = s_last_tick_ms;
    s_moving        = false;

    Serial.println("[motor] init OK (L298N module, timer-based positioning, no pot/limit)");
}

void motor_driver_apply(const MotorCommand_t& cmd) {
    s_dir  = cmd.direction;
    s_duty = cmd.pwm_duty;
    if (s_duty > MOTOR_PWM_MAX) s_duty = MOTOR_PWM_MAX;

    switch (s_dir) {
    case MOTOR_UP:
        ledcWrite(LEDC_CH_IN2, 0);
        ledcWrite(LEDC_CH_IN1, s_duty);
        break;
    case MOTOR_DOWN:
        ledcWrite(LEDC_CH_IN1, 0);
        ledcWrite(LEDC_CH_IN2, s_duty);
        break;
    case MOTOR_BRAKE:
        // Dynamic short-brake on the L298N: drive both inputs HIGH so both
        // motor terminals sit at the same rail; back-EMF is shorted through
        // the high-side switches and the rotor is braked. s_duty stays at the
        // commanded value (0), so the HMI reports 0 % *propulsive* duty while
        // braking — truthful, since no drive power is being applied to move the
        // deck.
        ledcWrite(LEDC_CH_IN1, MOTOR_PWM_MAX);
        ledcWrite(LEDC_CH_IN2, MOTOR_PWM_MAX);
        break;
    case MOTOR_COAST:
    case MOTOR_STOP:
    default:
        ledcWrite(LEDC_CH_IN1, 0);
        ledcWrite(LEDC_CH_IN2, 0);
        break;
    }

    // (Re)start the runaway timer only on the rising edge into a moving state
    // so that re-issuing the same direction does not keep resetting it.
    bool now_moving = (s_dir == MOTOR_UP || s_dir == MOTOR_DOWN);
    if (now_moving && !s_moving) {
        s_move_start_ms = millis();
    }
    s_moving = now_moving;
}
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

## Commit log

2026-04-27 Set up base directory structure and add initial KiCad PCB files
    [ConnectorsSafety.kicad_sch, ESP32Module.kicad_sch, MotorDrivers.kicad_sch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]
2026-04-28 Added appropriate footprints to all components in the PCB
    [ConnectorsSafety.kicad_sch, ESP32Module.kicad_sch, MotorDrivers.kicad_sch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]
2026-04-28 chore: add .gitkeep to track empty directories
    This ensures that empty project structure directories like firmware and mechanical are tracked by Git and available in the remote repository.
2026-04-29 Updated to KiCAD 10.0 thus updated KiCAD files to the new versioin format
    [ConnectorsSafety.kicad_sch, ESP32Module.kicad_sch, MotorDrivers.kicad_sch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]
2026-04-29 Added proposal folder in docs with the latest proposal
    [vertical_lift_pcb.kicad_pcb]
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2026-05-01 docs: rewrite proposal for vertical-lift mechanism (cable + counterweight)
2026-05-01 cad: add common parameters module and tower_left/tower_right OpenSCAD sources
    [00_common.scad, 01_tower_left.scad, 02_tower_right.scad]
2026-05-01 cad: add bridge_deck_section, pulley_wheel and cable_guide OpenSCAD sources
    [03_bridge_deck_section.scad, 06_pulley_wheel.scad, 08_cable_guide.scad]
2026-05-01 cad: add counterweight_left/right, motor_mount and road_barrier sources
    [04_counterweight_left.scad, 05_counterweight_right.scad, 07_motor_mount.scad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]
2026-05-01 cad: add base_plate, pcb_enclosure, camera_mount, tft_display_mount and full assembly
    [10_base_plate_section.scad, 11_pcb_enclosure.scad, 12_camera_mount.scad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]
2026-05-01 cad: render 13 STLs for printing and 3MF assemblies for review
    [01_tower_left.stl, 02_tower_right.stl, 03_bridge_deck_section.stl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]
2026-05-01 docs: add cad/README_cad.md with print order and slicer profile
2026-05-01 firmware(motor): add motor_driver with BTS7960 LEDC PWM, Hall encoder, ADC current sense
2026-05-01 firmware(sensors): add dual HC-SR04 ultrasonic with direction inference
2026-05-01 firmware(vision): add UART2 vision_link with ArduinoJson parser, heartbeat timeout
2026-05-01 firmware_cam: ESP32-CAM companion firmware with frame-difference motion detection
2026-05-01 firmware(traffic): add 74HC595 traffic_lights for 6-LED chain (road + marine)
2026-05-01 firmware(buzzer): add LEDC ch5 buzzer with chirp / fault / e-stop patterns
    [buzzer.cpp]
2026-05-01 firmware(hmi): TFT_eSPI + LVGL 9.x bringup with double-buffered DMA flush, XPT2046 touch, async-call thread-safety, 5 screen template stubs (creative-liberty for M4)
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2026-05-01 firmware(safety): add interlocks (E-stop ISR, relay coil, barrier servos) and force-safe path
2026-05-01 bom: add procurement spreadsheet with 4 sections, formulas, KES totals (grand total KES 24,465)
    [VLB_Group5_BOM.xlsx]
2026-05-01 docs: add M2 Eugene - Mechanism & motor calibration guide
2026-05-01 docs: add M3 Cindy - Vision & sensors guide
2026-05-01 docs: add M5 Ian - PCB, power & safety firmware guide
2026-05-02 chore(pcb): update KiCad project metadata to v4 format
2026-05-02 chore: rename Group 5 to Group 7, simplify to single-branch workflow
    - Replace all "Group 5" references with "Group 7" across README,
    firmware source, docs, and member guides
    - Rename bom/VLB_Group5_BOM.xlsx to bom/VLB_Group7_BOM.xlsx
    - Simplify Git workflow from feature-branch + PR model to direct-to-main
    single-branch workflow for team accessibility
    - Remove branch naming, PR etiquette, squash-merge, and branch deletion
    sections from README
    - All 13 feature branches already deleted from local and remote
    [VLB_Group7_BOM.xlsx]
2026-05-02 Updated the BOM on number of ultrasound sensors
    [VLB_Group7_BOM.xlsx]
2026-05-02 firmware(sensors): implement quad HC-SR04 with upstream/downstream pairs
    Expand ultrasonic subsystem from 2 sensors to 4, arranged as two pairs:
    - Upstream pair (US1+US2): detects vessels approaching from upstream
    - Downstream pair (US3+US4): detects vessels approaching from downstream
    Each pair uses 3 cm beam spacing and a 5-sample history ring to infer
    vessel direction (approaching vs leaving). Bridge opens when either
    pair detects an approaching vessel. EVT_VEHICLE_CLEARED only fires
    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
2026-05-02 feat(counterweight): add simulated dynamic counterweight system
    Add a software-only simulation of a pump-and-drain water counterweight
    system. No physical hardware changes — the static lead counterweights
    remain on the rig. The simulation models two water tanks (left/right)
    that fill and drain to a target level, with configurable fill/drain
    rates and tolerance.
    New module: firmware/src/counterweight/ (counterweight.h, counterweight.cpp)
    - CwTankSim_t and CounterweightStatus_t types in system_types.h
    - EVT_CW_READY event gates ROAD_CLEARING → RAISING transition
    - task_counterweight runs at 20 Hz on Core 0
    - FSM triggers counterweight balancing before raise cycle
    HMI changes:
    - Telemetry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
    [display.cpp, fsm_actions.cpp, main.cpp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]
2026-05-02 fix: resolve pin name mismatches, DRV8871→BTS7960, BOM total
    - Add backward-compat alias section to pin_config.h (16 aliases) so all
    .cpp files compile against the canonical pin names
    - Define PIN_V12_SENSE and PIN_V5_SENSE for fault_register.cpp
    - Fix LEDC_MOTOR_RES_BITS 10→13 to match MOTOR_PWM_MAX 8191
    - Replace all DRV8871 references with BTS7960 in docs and source
    - Fix silkscreen ident VLB-G5→VLB-G7 in electronics design doc
    - Correct BOM grand total KES 24,465→24,825 in README
    - Add PIN_BTN_LADDER alias for input.cpp
    [motor_driver.cpp, pin_config.h]
2026-05-02 fix(safety): remove rail/operator-panel ADC scheme — impedance collision (v2.1)
    Rail voltage monitoring (PIN_V12_SENSE/PIN_V5_SENSE) and the front-panel
    resistor-ladder buttons (PIN_BTN_LADDER) were aliased to GPIO 34/35, which
    are already owned by the BTS7960 IS pin and the deck-position pot. Both
    present low source impedance at all times — a high-impedance divider on
    the same pin gets swamped. Software multiplexing by FSM state cannot fix
    the analog conflict; the previous code would have produced systematically
    wrong rail readings (motor-coupled noise, not rail voltage).
    Changes:
    - pin_config.h: remove PIN_V12_SENSE/PIN_V5_SENSE/PIN_OP_PANEL_ADC defines
    and PIN_BTN_LADDER alias; bum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
    [fault_register.cpp, pin_config.h, system_types.h]
2026-05-03 docs(member_guides): comprehensive rewrite — assume no prior knowledge
    All 5 member guides expanded to be followable end-to-end with no gaps:
    M1 George (FSM): full event/guard/action walkthrough, dev harness, recipes
    for adding states/events/guards/faults, integration session protocol,
    watchdog management, demo script template. ~612 lines.
    M2 Eugene (mechanism): per-STL print queue with slicer settings, mechanical
    assembly step-by-step with photo-doc requirement, BTS7960 wiring with
    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
2026-05-03 Updating M5 guide and remote repo in general
    [ConnectorsSafety.kicad_sch, ESP32Module.kicad_sch, MotorDrivers.kicad_sch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]
2026-05-04 Updated simulation guide for member 3 to implement the quad ultrasonic sensor configuration
2026-05-10 v2.2 polish #6: tell the truth about ultrasonic functionality
    Tracing the pin-sharing matrix through end-to-end exposed that the L8
    description was too generous to v2.2 reality:
    - US1 + US3 TRIG pads (GPIO 5 + GPIO 22) host the LEDC PWM signals for
    the two barrier servos. Once interlocks_init attaches each servo,
    the GPIO matrix routes LEDC to the pad permanently and the
    digitalWrite(TRIG, HIGH/LOW) calls in sensors_ultrasonic_tick no
    longer reach the SR04. With no trigger out, no echo comes back —
    these sensors silently report 0xFFFF (no echo) regardless of my
    earlier ECHO time-multiplex fix in traffic_lights.cpp.
    - US2 ECHO is permanently dead because GPIO 21 must hold OUTPU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
2026-05-10 v2.2 polish #9: drop stale "(M1's TODO)" annotation
    EVT_OPERATOR_HOLD is wired in v2.2 — pressing the HOLD button
    (BTN3 on the operator panel, or the on-screen HOLD button) transitions
    the FSM to STATE_RAISED_HOLD from RAISING / LOWERING. The FAULTS-screen
    table in M4 still flagged this as outstanding M1 work; updated to
    describe the actual current behaviour.
2026-05-10 v3.0 architectural overhaul: UI parity, quad-ultrasonics, and breadboard guides
    - Pin Configuration: Resolved critical L4/L8 pin conflicts by multiplexing the HC-SR04 ultrasonic triggers onto a single shared GPIO (GPIO 5). The quad-sensor array is now fully functional.
    - HMI Parity: Completely rewrote display.cpp to port the LVGL 9 simulation UI into the physical ESP32 firmware (Light Mode, Radar, Auto Mode, Counterweights, Telemetry).
    - Motor Calibration: Replaced dynamic boot auto-zeroing with a hardcoded CAL_ADC_ZERO_DEFAULT absolute calibration constant to fix FSM position desyncs upon reboot.
    - Testing: Added exhaustive step-by-step breadboard prototyping guides for M1-M5 (member_guides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
    [display.cpp, fault_register.cpp, main.cpp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]
2026-05-10 docs: align breadboard guides with L293D BOM
    - Replaced BTS7960 references with L293D in M2 and M5 guides to match official BOM.
2026-05-13 Fixed the screen touch map to accurately align with the rendered UI
    [display.cpp]
2026-05-15 feat: hmi marine UI, servo smooth sweep, shift register hardened
2026-05-15 docs: finalize pin-to-pin wiring guides and vision logic refactoring
2026-05-16 refactor: migrate from HC-SR04 ultrasonics to Laser Break-Beam sensors
2026-05-16 refactor: remove vision module, switch to manual mode with vivid UI alert
2026-05-16 fix(hmi): resolve LVGL watchdog crash by replacing DMA flush with synchronous pushImage
    [display.cpp]
2026-05-19 fix(safety): remove DEV MOCKs, enable physical E-Stop and stall logic, guard against lowering on vessel approach
    [interlocks.cpp, laser.cpp, main.cpp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]
2026-05-19 docs: transition to physical assembly phase, document reverted mock bypasses
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2026-06-05 feat(hmi): complete 4-tab LVGL UI; fix(pin): servo GPIO3→16; docs: fill README
    - hmi/display.cpp: implement full HOME/OPS/CW/SET tab layout with deck bar,
    marine LEDs, traffic LEDs, RAISE/LOWER/HOLD buttons, motor arc gauge,
    counterweight tank bars, dark-mode switch, and header-click popup
    - hmi/display.h: remove unused HMI_CMD_BRIGHTNESS_UP/DOWN (BL hardware-fixed)
    - pin_config.h v3.0: move PIN_SERVO_LEFT/RIGHT from GPIO3 to GPIO16, freeing
    UART0 RX for serial monitor; remove PIN_VISION_RX / PIN_UART2_RX alias
    - system_types.h: remove hmi_brightness and auto_mode_active from SharedStatus_t
    - platformio.ini: remove duplicate TOUCH_CS flag, lower SPI to 20 MHz, add
    SPI_READ_FREQUENC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
    [display.cpp, pin_config.h, system_types.h]
2026-06-05 refactor(firmware): L298N + timer-based positioning, deck-synced counterweight
    Motor/positioning:
    - Migrate L293D -> L298N across firmware, comments, README, docs
    - Replace pot + limit switches with timer-based deck positioning
    (DECK_RAISE_TIME_MS/DECK_LOWER_TIME_MS, pinned to end-stops each traverse)
    - Repurpose FAULT_STALL as a run-time runaway guard (no feedback)
    - GPIO 35/39 retained as reserved spares (pin map frozen)
    Counterweight:
    - Slave tank levels to deck height (direct/proportional sync)
    - Replace counterweight_set_target() with counterweight_prepare() gate-arm
    Safety/traffic:
    - Implement FAULT_BARRIER_TIMEOUT watchdog in interlocks
    - Implement marine signal stack (74HC595 Q3-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
    [display.cpp, fault_register.cpp, fsm_actions.cpp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]
2026-06-09 fix(firmware): module review — safety logic, dead-code sweep, marine HMI
    Cross-module safety/logic:
    - FSM: gate FAULT/ESTOP recovery on new fsm_guard_deck_down() so IDLE
    (road green + barriers open) is never entered with the deck raised;
    recover to RAISED_HOLD instead and require a manual LOWER.
    - FSM: re-evaluate safe_to_lower every tick during LOWERING and abort to
    RAISED_HOLD if a vessel appears mid-descent (was a one-shot guard).
    - watchdog/main: task_safety now subscribes to + feeds the hardware TWDT,
    so a hang in the task that runs the software watchdog is still caught.
    Correctness:
    - laser: require BOTH beams to break in sequence before asserting a
    direction (a single stu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
    [buzzer.cpp, display.cpp, fsm_actions.cpp]
2026-06-13 refactor(traffic): remove marine lights, self-heal 595 output; tune motor timer
    - traffic: remove unimplemented marine traffic lights from firmware + HMI
    (traffic_lights, fsm_actions, display SIGNALS card, README); drop the
    leftover remove_marine.py scratch script.
    - traffic: re-assert the 74HC595 at ~2 Hz so a single corrupted latch (3.3V
    rail dip on relay switch / breadboard noise) self-corrects instead of
    sticking until the next state change.
    - motor: set deck raise/lower timer to 14 s (DECK_RAISE/LOWER_TIME_MS); the
    runaway/stall guard now trips at 16 s.
    - pin_config: comment out unused PIN_LIMIT_ANYHIT (39) reserved define.
    Note: the 74HC595 traffic LEDs still misbehave on ha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
    [display.cpp, fsm_actions.cpp, pin_config.h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]
